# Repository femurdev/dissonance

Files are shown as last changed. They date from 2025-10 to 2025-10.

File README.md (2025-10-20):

# Dissonance

**Dissonance** is a network-controlled bell system that lets users trigger real bells through a web interface. It connects a web app to physical bell controllers via wireless communication, enabling musical or alerting patterns to be played remotely.

## Features
- 🛜 Control physical bells wirelessly from any browser  
- 🎵 Trigger individual notes or full sequences  
- 🌐 Simple web interface for live interaction  
- ⚙️ Modular hardware and software design  
- 🧾 Bill of Materials (see `BOM.csv`) for easy replication  

## Architecture
1. **Frontend Web Interface**
   - Built with standard web technologies.
   - Sends bell commands via a backend BLE API.
2. **Backend Bells**
   - Receives user actions over BLE.
   - Sends control messages to all bell nodes.
   - See image below:
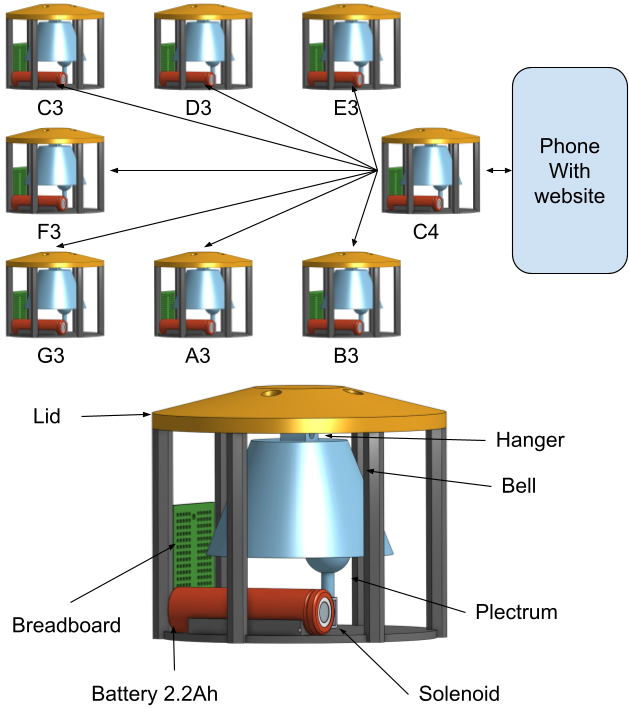
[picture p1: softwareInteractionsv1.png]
Bell Connections

3. **Bell Nodes (Hardware)**
   - Each node controls a physical bell and actuator.
   - Uses BLE protocol.
   - Receives and executes play commands.

## Setup
1. Clone the repository:
   ```bash
   git clone https://github.com/femurdev/dissonance.git
   cd dissonance
   ```
2. Review hardware components in `BOM.csv`.
3. Flash firmware to each bell node (see `firmware/` if available).
4. Start the backend server (instructions TBD).
5. Open the web UI in your browser and start ringing bells!

## Project Status
> Currently under early development.  
> See [`JOURNAL.md`](JOURNAL.md) for design notes, progress, and experiments.

## License
This project is released under the [CC0-1.0 License](LICENSE), meaning it is public domain.

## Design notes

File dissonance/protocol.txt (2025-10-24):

1) Architecture & workflow

C3 (Host)

Acts as Wi-Fi access point (or station on same network) that the other ESP32s and PC join.

Runs a small TCP server so the PC can reliably send schedules/commands.

Broadcasts periodic TIME beacons via UDP and rebroadcasts the PC’s PLAY note <target_unix_time> commands to all ESPs via UDP.

Other ESP32s (D4, E4, F4, G4, A4, B4, C5)

Join C3’s network as stations.

Listen on UDP port for both TIME beacons and PLAY messages.

Maintain a local clock offset (host_time − local_time) using incoming TIME beacons and smoothing.

When a PLAY command arrives containing a future absolute unix timestamp, schedule playback locally at that absolute time (local_time + offset).

PC (Conductor)

Connects to C3 via TCP, sends PLAY commands with target_time = now + schedule_ahead (e.g., 300–700 ms).

Use TCP so commands are received reliably by C3; C3 then broadcasts UDP to all nodes simultaneously.

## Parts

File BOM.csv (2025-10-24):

Index | Quantity | Part Number | Manufacturer Part Number | Description | Available | Backorder | Unit Price | Extended Price USD | Provider | Link
1.0 | 8 | SBB170-ND | SBB170 | BREADBOARD GENERAL PURPOSE PTH | 8 | 0 | 1.99 | 15.92 | Digikey | https://www.digikey.com/
2.0 | 8 | 1597-113991054-ND | 113991054 | XIAO ESP32C3 | 8 | 0 | 4.99 | 39.92 | Digikey | https://www.digikey.com/
3.0 | 8 | IRLZ44NPBF-ND | IRLZ44NPBF | MOSFET N-CH 55V 47A TO220AB | 8 | 0 | 1.53 | 12.24 | Digikey | https://www.digikey.com/
4.0 | 8 | 1568-11015-ND | 11015 | SOLENOID PUSH INTERMITTENT 5V | 8 | 0 | 6.5 | 52.0 | Digikey | https://www.digikey.com/
5.0 | 8 | 3544-USE-18650-2200PCBJST-ND | USE-18650-2200PCBJST | BATTERY LITH-ION 3.7V 2.2AH 1865 | 8 | 0 | 8.99 | 71.92 | Digikey | https://www.digikey.com/
6.0 | 16 | 455-1704-ND | B2B-PH-K-S | CONN HEADER VERT 2POS 2MM | 16 | 0 | 0.083 | 1.33 | Digikey | https://www.digikey.com/
7.0 | 10 | 497-6610-1-ND | 1N5819 | DIODE SCHOTTKY 40V 1A DO41 | 10 | 0 | 0.095 | 0.95 | Digikey | https://www.digikey.com/
8.0 | 4 | 1597-102010490-ND | 102010490 | 7-PIN MALE HEADER FOR XIAO 5PACK | 4 | 0 | 0.24 | 0.96 | Digikey | https://www.digikey.com/
9.0 | 8 | B0836J8LR4 | N/A | 8PCS 2A 5V Charge Discharge Integrated Module 3.7V 4.2V for 18650 Lithium Battery Charging Boost Mobile Power Supply Charge and Discharge Protection Converter Protection PCB Board Module | Yes | No | 1.24875 | 9.99 | Amazon | https://www.amazon.com/gp/product/B0836J8LR4?smid=A39S0U3UP1U7UG&psc=1

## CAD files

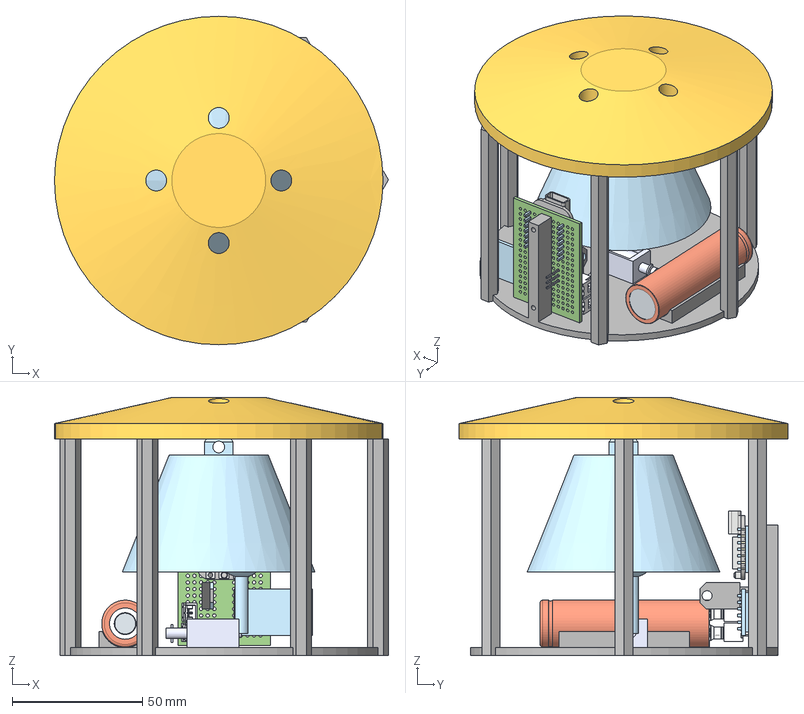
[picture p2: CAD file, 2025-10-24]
Assembly.step
128.1 x 126.0 x 99.0 mm
base
lid
ROB-11015 x 2
SEEED Esp32 C3 mini v2
CONNECTOR,JST PH SERIES,FEMALE_02 (PHR-2) x 2
JST - XH - Thru - 2Pin - 2.5mm (Genuine) v1 x 2
TIP32C Transistor

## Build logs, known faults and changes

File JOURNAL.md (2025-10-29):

<!--
  ===================    !!READ THIS NOTICE!!   ====================
  DO NOT edit this file manually. Your changes WILL BE OVERWRITTEN!
  This journal is auto generated and updated by Hack Club Blueprint.
  To edit this file, please edit your journal entries on Blueprint.
  ==================================================================
-->

## 10/18/2025 - Testing setups  



I'm trying to build this out of existent parts only. I dug the old revision out of the box today. There are a few major requirements.
I know some parts I'm gonna need off the top of my head:
- 8x 3.7v LiPo batteries
- 8x 3.6v Relays
- 8x XAIO ESP32C3 Microcontrollers
- A lot of hot glue
I'll post back here once I've done more.

## 10/19/2025 9 AM - Deconstruction of old model  

These dang solenoids barely exist, there's one listing on Digiday that seems reliable and then a bunch of Amazon junk. 
Needed to take this apart as old version had servos burning out.
Anyway, I dismantled my previous revision of this project, stabbed myself twice in the process. **Note to self:** Don't use too much hot glue.


## 10/19/2025 11 AM - Inital parts list created  

Screenshot 2025-10-19 at 11.45.30 AM.png

After much deliberation, I created an initial parts list. Unfortunately, this parts list is much too long/expensive to do anything with. I'll continue to optimize it down. If you have any recommendations please contact at femurdev@gmail.com. Please & Thank you!  

## 10/19/2025 1 PM - Inner Bell Clip  

Screenshot 2025-10-19 at 12.25.33 PM.png

I measured and designed the inner bell clip, yet to fabricate, but I think it's looking good so far. Dependent on the bells you use, this may be different. My bells have a flat sop at the top that many others may not have. There's a bit of string required at the top too. This is like version 4 at this point, which is why it took an hour.

## 10/19/2025 10:43 PM - Rest of Build Design  

I got the rest of this model together (3d at least) but have yet to model out the interactions of the boards with each other / the website. I have a previous test that proves that this works, but unfortunately, I dismantled it and is part of a research project that I can't show without getting in trouble.
Anyway, here's the full thing:
Screenshot 2025-10-19 at 2.51.48 PM.png

## 10/19/2025 10:56 PM - Software Architechture Design  

Untitled drawing.png
Here's the rest of this project's outline. I'll be able to send more about this project once I get it approved. I hope this conveys the level of complexity within this project, as offsets must be accounted for and timings must be precise for the music to sound correct. Furthermore, I already bought the bells, which were 60 bucks alone. I intend to hook this up to a song machine with AI or MIDI input on a website which I will develop once this project is approved.  

## 10/23/2025 5 PM - Circuitboard CAD Assembly  

Screenshot 2025-10-23 at 5.56.00 PM.png

I designed a full assembly view for the bells now. I don't know how to do wires yet, so let me know if that level of an assembly view is required. Likewise, I learned why assemblies were important, because I almost ordered 2x the JH connectors. (MB) Definitely something I'll carry with me.
Secondly, I changed a major component (the 5v regulator) for a cheaper version. Hoping for some funding for this project, as I'm really getting excited about this now. I'll be back with a code + Full CAD update later.

P.S. Don't laugh, I had to teach myself Onshape Assembly studios to do this correctly! It was haphazardly placing parts in kind of the right place before.

## 10/23/2025 6 PM - Full CAD Complete  

Screenshot 2025-10-23 at 6.16.26 PM.png
I made my full cad model. I'm putting it up on GitHub for now, but I may rework it at some point later down the road to be in a handle shape. For now, here it is. I swear this process went 100x quicker because I knew what I was doing. It's fun now so I'll keep doing it.  

## 10/24/2025 6 AM - Tried Bluetooth  

Screenshot 2025-10-24 at 6.45.59 AM.png
I tried to code this in Bluetooth, but everything kept on breaking. I'm thinking that I'll use Wi-Fi now due to the low latency. Not only that, but I did come up with a cool way to program the notes for now. That's really it, this one was a fail. More when I get my homework done.

## 10/24/2025 3 PM - Wi-Fi connections  

Sorry that the pictures are straight code here, that's really the most exciting thing. The only other thing is two ESP32s. Wifi seems to work like a charm, though, so I'm going to keep using it. I can basically verify it. uploads and connects, but not much more without the components. (🙏 for grant)

_There's gonna be so much soldering. (to save money ofc)_ 
### 😰
Screenshot 2025-10-24 at 6.50.12 AM.png  

## 10/29/2025 - Learning Kicad  

I'm making a PCB for this project to help decrease costs. I have to say, it's like pipes/snake but still extremely challenging. I'm looking forward to producing it even though it is completely new to me.
I watched like 4 tutorials on KiCad and put together a battery-powered light for now. This is confusing at first
Screenshot 2025-10-29 at 8.09.21 AM

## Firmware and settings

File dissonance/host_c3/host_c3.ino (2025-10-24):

/* host_c3.ino -- run on ESP32-C3 (Host) */
#include <WiFi.h>
#include <WiFiClient.h>
#include <WiFiServer.h>
#include <WiFiUdp.h>

const char* ap_ssid = "ESP_MUSIC_AP";
const char* ap_pass = "pass1234"; // change for production

WiFiServer tcpServer(5000);
WiFiUDP udp;
const IPAddress broadcastIP(255,255,255,255);
const uint16_t UDP_PORT = 4210;
const unsigned long TIME_BEACON_MS = 1000UL; // beacon every 1s

unsigned long lastBeacon = 0;

// Host time base: when we receive SET_TIME <unix_float>, we compute:
//   baseUnixOffset = provided_time - (millis()/1000.0)
// so current host unix time = baseUnixOffset + (millis()/1000.0)
double baseUnixOffset = 0.0;
bool haveBaseUnix = false;

// Pending plays queue for the host itself (so the host can play the notes it schedules)
struct PendingPlay {
  String note;
  unsigned long execMs;
  bool active;
};
PendingPlay pendingPlays[8]; // small fixed-size queue; adjust if needed

void setup() {
  Serial.begin(115200);
  // Start SoftAP
  WiFi.mode(WIFI_AP);
  bool ok = WiFi.softAP(ap_ssid, ap_pass);
  Serial.printf("SoftAP started: %s, IP: %s\n", ap_ssid, WiFi.softAPIP().toString().c_str());
  tcpServer.begin();
  udp.begin(UDP_PORT); // bind to UDP port for sending
  lastBeacon = millis();
}

void sendTimeBeacon() {
  // Send: TIME <unix_seconds> <millis_part>
  // We prefer to send a consistent host unix time if we've been given SET_TIME by the conductor.
  double hostTime;
  if (haveBaseUnix) {
    hostTime = baseUnixOffset + ((double)millis() / 1000.0);
    unsigned long unixSec = (unsigned long)hostTime;
    unsigned long msPart = (unsigned long)((hostTime - (double)unixSec) * 1000.0 + 0.5);
    char buf[80];
    snprintf(buf, sizeof(buf), "TIME %lu %lu\n", unixSec, msPart);
    udp.beginPacket(broadcastIP, UDP_PORT);
    udp.write((uint8_t*)buf, strlen(buf));
    udp.endPacket();
  } else {
    // Fallback: use system time for seconds and local millis() for ms part.
    uint64_t nowUnix = (uint64_t)(time(nullptr));
    unsigned long ms = millis() % 1000;
    char buf[80];
    snprintf(buf, sizeof(buf), "TIME %llu %lu\n", (unsigned long long)nowUnix, ms);
    udp.beginPacket(broadcastIP, UDP_PORT);
    udp.write((uint8_t*)buf, strlen(buf));
    udp.endPacket();
  }
}

void broadcastPlay(const String &playLine) {
  // Forward PLAY lines as-is over UDP to all nodes
  udp.beginPacket(broadcastIP, UDP_PORT);
  udp.write((uint8_t*)playLine.c_str(), playLine.length());
  udp.endPacket();
  Serial.print("Broadcasted: "); Serial.println(playLine);
}

// Host-side play helper (prints and is a placeholder for actual sound output)
void playNoteHost(const String &note) {
  Serial.printf("HOST PLAYING note %s at local time %.3f\n", note.c_str(), (double)millis() / 1000.0);
  // TODO: map note -> actual sound trigger (GPIO, DAC, I2S, etc.) if host should output audio
}

// Schedule a play on the host itself (non-blocking)
void scheduleHostPlay(const String &note, double targetHostUnix) {
  double currentHostUnix = haveBaseUnix ? (baseUnixOffset + ((double)millis() / 1000.0)) : (double)time(nullptr);
  double delaySec = targetHostUnix - currentHostUnix;
  if (delaySec <= 0) {
    playNoteHost(note);
    return;
  }
  unsigned long execMs = millis() + (unsigned long)(delaySec * 1000.0 + 0.5);
  // enqueue into pendingPlays
  for (int i = 0; i < (int)(sizeof(pendingPlays) / sizeof(pendingPlays[0])); ++i) {
    if (!pendingPlays[i].active) {
      pendingPlays[i].note = note;
      pendingPlays[i].execMs = execMs;
      pendingPlays[i].active = true;
      Serial.printf("Scheduled host play %s at execMs=%lu\n", note.c_str(), execMs);
      return;
    }
  }
  // queue full -> play immediately as fallback
  Serial.println("Pending plays queue full; playing immediately on host");
  playNoteHost(note);
}

void handleTcpClient(WiFiClient &client) {
  // read TCP lines; each line should be e.g. "PLAY C4 1698700000.123\n"
  while (client.connected() && client.available()) {
    String line = client.readStringUntil('\n');
    if (line.length() == 0) continue;
    if (line.startsWith("PLAY ")) {
      // Broadcast to all nodes
      broadcastPlay(line + "\n");
      // Also schedule the host itself to play the note at the target time
      char noteStr[16];
      double target = 0.0;
      int n = sscanf(line.c_str(), "PLAY %15s %lf", noteStr, &target);
      if (n >= 2) {
        scheduleHostPlay(String(noteStr), target);
      } else {
        Serial.print("Malformed PLAY line: "); Serial.println(line);
      }
    } else if (line.startsWith("SET_TIME ")) {
      // Accept SET_TIME <unix_seconds_float> to set host's view of unix time
      // Compute baseUnixOffset such that baseUnixOffset + millis()/1000.0 == provided_time
      double t = 0.0;
      int n = sscanf(line.c_str(), "SET_TIME %lf", &t);
      if (n >= 1) {
        baseUnixOffset = t - ((double)millis() / 1000.0);
        haveBaseUnix = true;
        Serial.printf("SET_TIME applied. baseUnixOffset=%.6f\n", baseUnixOffset);
      } else {
        Serial.print("Malformed SET_TIME line: "); Serial.println(line);
      }
      // Broadcast SET_TIME to nodes so they can sync too
      broadcastPlay(line + "\n");
    } else {
      // ignore or log other commands
      Serial.print("TCP recv: "); Serial.println(line);
    }
  }
}

void loop() {
  // Accept TCP connections and read commands
  WiFiClient client = tcpServer.available();
  if (client) {
    Serial.println("PC connected via TCP");
    // handle in-line; for production you'd want to keep connection open in a task
    while (client.connected()) {
      if (client.available()) handleTcpClient(client);
      // optionally break if no data for a while
      delay(5);
    }
    client.stop();
    Serial.println("PC disconnected");
  }

  // Periodic time beacon
  unsigned long now = millis();
  if (now - lastBeacon >= TIME_BEACON_MS) {
    sendTimeBeacon();
    lastBeacon = now;
  }

  // Check pending host plays and fire any that are due
  unsigned long curMs = millis();
  for (int i = 0; i < (int)(sizeof(pendingPlays) / sizeof(pendingPlays[0])); ++i) {
    if (pendingPlays[i].active && (long)(curMs - pendingPlays[i].execMs) >= 0) {
      // due (handles wraparound)
      playNoteHost(pendingPlays[i].note);
      pendingPlays[i].active = false;
    }
  }

  // small delay to yield
  delay(2);
}

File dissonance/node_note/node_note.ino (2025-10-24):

/* note_node.ino -- run on ESP32 note nodes */
#include <WiFi.h>
#include <WiFiUdp.h>

const char* ssid = "ESP_MUSIC_AP";
const char* pass = "pass1234";

WiFiUDP udp;
const uint16_t UDP_PORT = 4210;

double clockOffset = 0.0;   // host_unix_time - (millis()/1000.0)
const double SMOOTH_ALPHA = 0.2; // smoothing factor for offset

void playNote(const String &note) {
  Serial.printf("PLAYING note %s at local time %.3f (offset %.3f)\n",
                note.c_str(), (double)millis()/1000.0, clockOffset);
  // TODO: map note -> actual sound trigger (GPIO, DAC, I2S, etc.)
}

void schedulePlay(const String &note, double targetHostUnix) {
  double localNow = (double)millis() / 1000.0;
  double localTarget = targetHostUnix - clockOffset; // target in local epoch-seconds
  double delaySec = localTarget - localNow;
  if (delaySec <= 0) {
    // If negative, play immediately
    playNote(note);
  } else {
    // Non-blocking scheduling: spawn a simple task using millis() check
    unsigned long execTimeMs = millis() + (unsigned long)(delaySec * 1000.0 + 0.5);
    // simple busy-scheduler: push to a small queue (here simplified: blocking delay)
    // For robust operation, use a timer or task queue. Simpler: create a lambda-like loop.
    while (millis() < execTimeMs) { delay(1); } // OK for small numbers of nodes; replace for heavy use
    playNote(note);
  }
}

void processUdpPacket(char *buf, int len) {
  buf[len] = '\0';
  String s = String(buf);
  s.trim();
  if (s.startsWith("TIME ")) {
    // TIME <unix_seconds> <millis_part>
    // Example: TIME 1698700000 12345
    // We'll compute hostUnixApprox = unix_seconds + millis_part/1000
    char tag[6];
    unsigned long msPart = 0;
    double unixSec = 0.0;
    sscanf(buf, "%5s %lf %lu", tag, &unixSec, &msPart);
    double hostTime = unixSec + (msPart / 1000.0);
    double localNow = (double)millis() / 1000.0;
    double newOffset = hostTime - localNow;
    // Exponential smoothing
    clockOffset = SMOOTH_ALPHA * newOffset + (1.0 - SMOOTH_ALPHA) * clockOffset;
    // Serial
    Serial.printf("TIME beacon: host=%.3f local=%.3f offset=%.6f\n", hostTime, localNow, clockOffset);
  } else if (s.startsWith("PLAY ")) {
    // PLAY <note> <target_unix_time>
    // e.g. PLAY C4 1698700000.823
    char noteStr[16];
    double target = 0.0;
    int n = sscanf(buf, "PLAY %15s %lf", noteStr, &target);
    if (n >= 2) {
      String note = String(noteStr);
      Serial.printf("Received PLAY %s @ %.3f (host unix)\n", note.c_str(), target);
      schedulePlay(note, target);
    }
  } else if (s.startsWith("SET_TIME ")) {
    // optional: host instructs a direct SET_TIME <unix_float>
    double t;
    sscanf(buf, "SET_TIME %lf", &t);
    double localNow = (double)millis() / 1000.0;
    double newOffset = t - localNow;
    clockOffset = newOffset;
    Serial.printf("SET_TIME applied. Offset now %.6f\n", clockOffset);
  }
}

void setup() {
  Serial.begin(115200);
  WiFi.mode(WIFI_STA);
  WiFi.begin(ssid, pass);
  Serial.printf("Connecting to %s\n", ssid);
  while (WiFi.status() != WL_CONNECTED) { delay(200); Serial.print("."); }
  Serial.println("\nConnected, IP: " + WiFi.localIP().toString());
  udp.begin(UDP_PORT);
  Serial.printf("Listening UDP on %d\n", UDP_PORT);
}

void loop() {
  int packetSize = udp.parsePacket();
  if (packetSize) {
    static char buf[200];
    int len = udp.read(buf, sizeof(buf)-1);
    if (len > 0) processUdpPacket(buf, len);
  }
  delay(1);
}
